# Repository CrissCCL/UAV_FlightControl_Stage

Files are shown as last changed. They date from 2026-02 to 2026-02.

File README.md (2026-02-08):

# 🧠🛩️ UAV Flight Control Stage — Teensy Carrier + Dual IMU (I2C)








## Overview

This repository documents the **Flight Control Stage PCB**, a custom carrier board
designed to integrate sensing, command, and actuation interfaces for a modular UAV platform.

The goal of this stage is to provide a **clean and reliable hardware foundation**
for embedded flight control electronics, concentrating all signal routing and I/O
on a dedicated board while keeping the **power distribution stage electrically separated**.

This revision replaces the previous single-IMU layout with a **redundant dual-IMU
architecture (BMI088 + ICM-42605)** connected through independent I²C buses to improve
measurement reliability and fault tolerance.

This hardware revision has been validated using a **Teensy 4.0** microcontroller as the target flight-control MCU.

## 📂 Contents

- `/Hardware` → Schematics, PCB layout, Gerbers
- `/test_dual_angle_failover` → Embedded test firmware (dual-IMU fault injection, validation utilities)

## 🧩 System Architecture

<p align="center">
  
</p>

## 🧩 Modular UAV Architecture

The UAV electronics are intentionally divided into **two independent hardware stages**:

| Stage | Responsibility |
|---|---|
| **Flight Control Stage (this repo)** | Sensing + control + I/O |
| **Power Stage** | Power distribution & regulation |

### Flight Control Stage Composition

This board integrates:

- Teensy 4.x carrier board (real-time control MCU)
- Dual IMU module (BMI088 + ICM-42605)
- RC input interface
- 4× PWM outputs for ESCs
- UART telemetry/debug

### Why separation?

Separating **control electronics** from **power electronics** provides:

- lower electrical noise coupling  
- improved signal integrity  
- safer power handling  
- easier maintenance and board replacement  
- faster hardware iteration

Dedicated power board:  
👉 https://github.com/CrissCCL/UAV_PowerStage

## ✨ Key Features

- Dual IMU redundancy (**BMI088 + ICM-42605**) over **I²C ×2**
- Real-time embedded control on Teensy 4.x
- 1× RC input
- 4× PWM outputs
- UART telemetry interface
- Physically isolated from power stage
- Mature **V5 hardware revision**, validated through multiple control iterations

## 🧪 Tested Platform

- **MCU:** Teensy 4.0  
- **Test mode:** Bench testing (no flight)  
- **Fault injection:** Firmware-controlled via UART  

## 🧪 Dual-IMU Fault Injection & Validation

To validate the robustness of the **redundant dual-IMU architecture**, a **firmware-based fault injection framework** was implemented on the Flight Control Stage.

Instead of relying on physical disconnections or uncontrolled hardware failures, IMU faults are **intentionally emulated in firmware**, enabling deterministic, repeatable, and safe validation of the sensing and fallback logic.

### 🎯 Validation Objectives

- Verify **fault detection** on each IMU (BMI088 / ICM-42605)
- Validate **primary / secondary IMU selection logic**
- Confirm correct **telemetry reporting** under fault conditions
- Observe system behavior during **degraded sensing scenarios**

### 🔧 Emulated Fault Modes

The firmware allows selective injection of failures on either IMU, including:

- IMU not responding (communication failure)
- Frozen sensor data (stuck output)
- Corrupted or invalid measurements
- Forced mismatch between redundant sensors

These modes reproduce realistic sensor failure scenarios without modifying or stressing the hardware.

### 🧠 System Behavior Under Test

During fault injection, the following mechanisms are evaluated:

- IMU health monitoring
- Mismatch detection between redundant sensors
- Automatic fallback to the alternate IMU
- Consistent reporting through UART telemetry and monitoring interfaces

This validation strategy allows early verification of **fault-tolerant sensing behavior** before flight testing.

### ✅ Benefits of Firmware-Based Fault Injection

- Fully repeatable and controllable tests  
- No physical stress on sensors or connectors  
- Faster validation cycles  
- Increased confidence in flight-control sensing reliability  

> This approach is a key step toward a **robust and maintainable flight control sensing architecture**, suitable for real-world UAV operation.

### 📈 Experimental Results — IMU Fault Injection

The following plot shows the system response during **firmware-emulated IMU fault scenarios**.

It illustrates:

- Real-time attitude estimation from both IMUs
- Detection of inconsistent or invalid sensor data
- Automatic switching between primary and secondary IMU
- Continuity of the estimated state during sensor failure events

<p align="center">
  imu_failover_test
</p>

<p align="center">
  <sub>
    Dual-IMU fault injection test — mismatch detection and automatic IMU fallback under emulated failure conditions
  </sub>
</p>
> Note: The test was performed with the UAV mechanically fixed on a test bench.
> IMU failures were emulated in firmware to ensure repeatability, safety, and deterministic validation.

During the test, faults were injected dynamically via firmware commands, without any hardware disconnection.
The system maintained valid state estimation while transparently switching between sensors, confirming the
correct operation of the redundancy and failover logic.

### 🧾 Fault Injection Control Interface (Serial Commands)

IMU fault scenarios are triggered via **serial commands**, allowing controlled and repeatable testing without hardware modification.

Faults are injected at runtime through the **UART serial monitor**, using newline-terminated commands (`\n`).

#### Supported Commands
- F0 -> No fault (normal operation)
- F1 -> BMI088 dead (bmi_data_ok = 0)
- F2 -> ICM-42605 dead (icm_data_ok = 0)
- F3 -> BMI088 data corruption (forces mismatch)
- F4 -> ICM-42605 data corruption
- F5 -> BMI088 stuck output (frozen data)
- F6 -> ICM-42605 stuck output (frozen data)
- F3,5000 -> Apply F3 for 5000 ms, then automatically return to F0

#### Usage Notes

- All commands must be terminated with `\n`
- Timed fault injection (`Fx,<time_ms>`) allows transient failure testing
- Commands can be issued dynamically during operation
- No hardware reset or reconnection is required between tests

This interface enables **deterministic validation of IMU redundancy, fault detection, and failover behavior** under realistic failure conditions.

> The firmware implementation for fault injection is available under `/test_dual_angle_failover/`.

## 🔌 Hardware Interfaces

| Interface | Qty | Description |
|---|----|---|
| Dual IMU (BMI088 + ICM-42605) | 1 | Two independent I²C buses |
| RC Input | 1 | Pilot command |
| PWM Outputs | 4 | Propulsion control |
| UART | 1 | Telemetry / debug |
| Teensy Socket | 1 | MCU carrier |

## 🖼️ PCB Render Visualization

<table>
  <tr>
    <td align="center">
      flight control stage top<br>
      <sub>Top View</sub>
    </td>
    <td align="center">
      flight control stage bottom<br>
      <sub>Bottom View</sub>
    </td>
  </tr>
</table>

## ⚡ Physical Prototype (V5 Installed on UAV)

The **V5 prototype** is directly integrated into the UAV for **full-system validation**.

Given the maturity of the control architecture, this stage is deployed directly for:

- flight control testing  
- system integration  
- real-time experimentation  

The following image shows the complete setup of the **prototype version V1**:

<table>
  <tr>
    <td align="center">
      light control stage<br>
      <sub> light control stage </sub>
    </td>
    <td align="center">
        Flight control stage + MCU<br>
      <sub> Flight control stage + MCU </sub>
    </td>
  </tr>
</table>

## 🔗 Related Repositories

- UAV platform main repository: https://github.com/CrissCCL/DIY_UAV
- Power stage PCB: https://github.com/CrissCCL/UAV_PowerStage
- Dual IMU evaluation module (sensor characterization and early validation):  
  https://github.com/CrissCCL/UAV_Dual_IMU

## ⚠️ Disclaimer

Educational and experimental use only.
Always follow safe practices when working with UAV propulsion systems.

## 🤝 Support Projects

Support my work on Patreon:  
https://www.patreon.com/c/CrissCCL

## 📜 License

MIT License

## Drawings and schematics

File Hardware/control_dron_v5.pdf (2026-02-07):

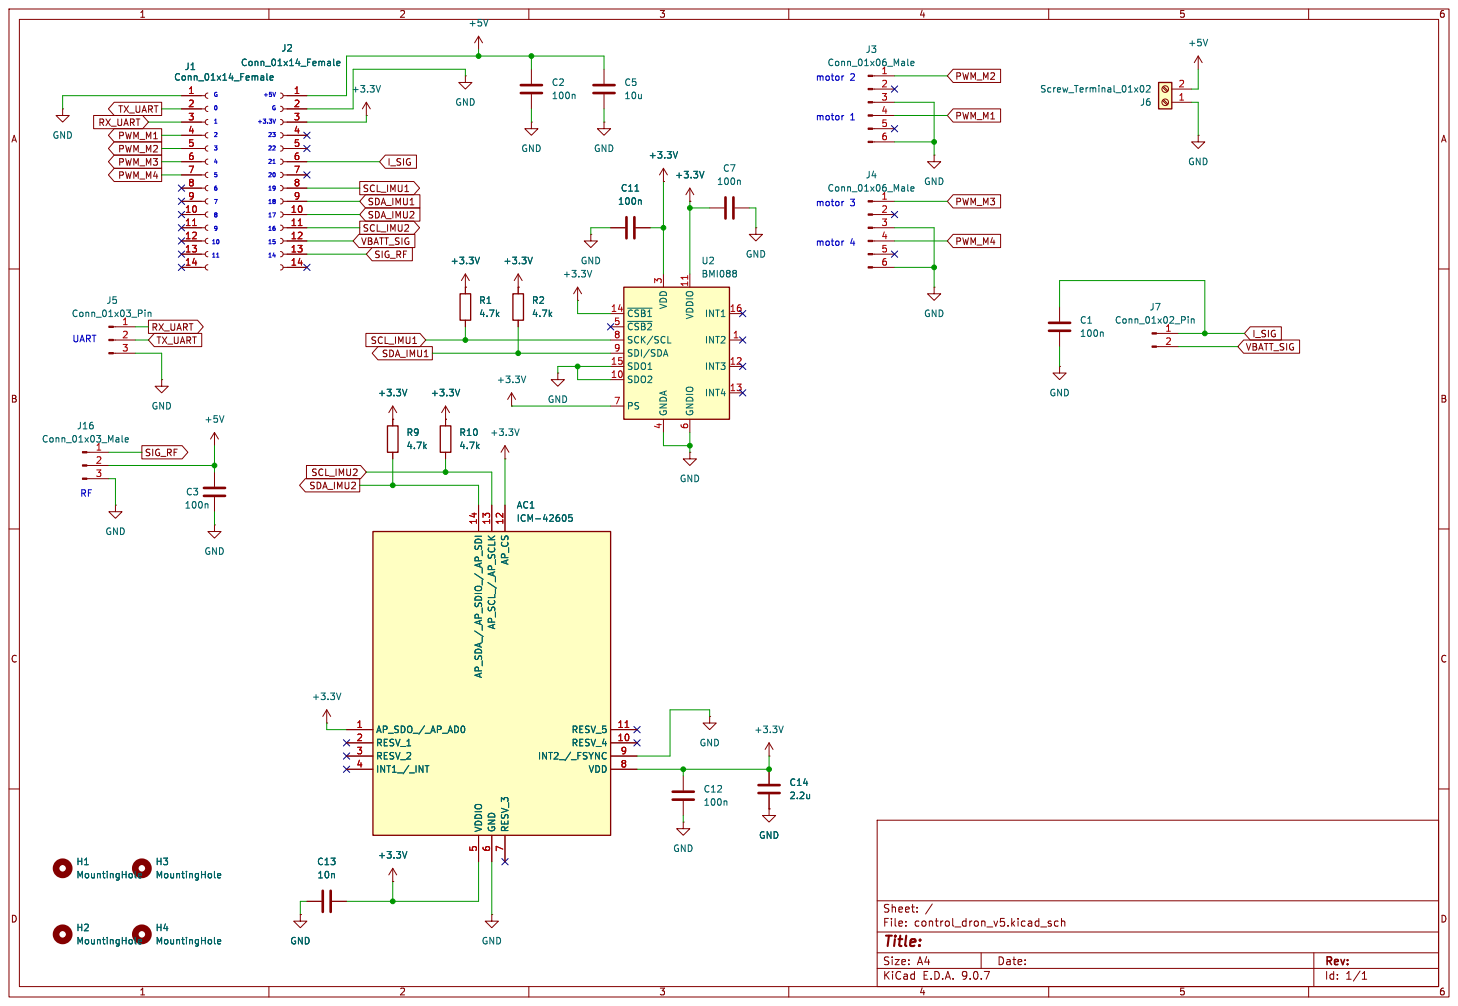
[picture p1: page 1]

Id: 1/1 Title: File: control_dron_v5.kicad_sch Sheet: /

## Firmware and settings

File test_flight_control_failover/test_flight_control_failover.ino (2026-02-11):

#include <Arduino.h>
#include <Wire.h>
#include <string.h>
#include <stdlib.h>

// ---- FIX Arduino autoprototyper (DO NOT DELETE) ----
enum FaultMode : uint8_t;
enum ImuSelect : uint8_t;
// -----------------------------------------------

/*
  =====================================================
  Dual IMU (BMI088 + ICM-42605) + Auto Failover + Fault Injection (Serial "F")
  Target: Teensy 4.x

  FIX applied:
  - Robust IMU init (ping + retries + proper post-reset delays)
  - ICM WHO_AM_I polling after reset (main cause of false FAIL at boot)
  =====================================================
*/

// =====================================================
// IMU selection
// =====================================================
enum ImuSelect : uint8_t { IMU_PRIMARY_BMI = 0, IMU_PRIMARY_ICM = 1 };
static ImuSelect PRIMARY_IMU = IMU_PRIMARY_BMI;

// =====================================================
// Fault injection
// =====================================================
enum FaultMode : uint8_t {
  FAULT_NONE = 0,
  FAULT_BMI_DEAD = 1,
  FAULT_ICM_DEAD = 2,
  FAULT_BMI_CORRUPT = 3,
  FAULT_ICM_CORRUPT = 4,
  FAULT_BMI_STUCK = 5,
  FAULT_ICM_STUCK = 6
};

static FaultMode faultMode = FAULT_NONE;
static uint32_t fault_until_ms = 0; // 0=infinite

static void set_fault(FaultMode m, uint32_t duration_ms) {
  faultMode = m;
  fault_until_ms = (duration_ms > 0) ? (millis() + duration_ms) : 0;
}

static void fault_tick_auto_clear() {
  if (fault_until_ms != 0 && (int32_t)(millis() - fault_until_ms) >= 0) {
    faultMode = FAULT_NONE;
    fault_until_ms = 0;
  }
}

// =====================================================
// I2C addresses
// =====================================================
static const uint8_t BMI_ACC_ADDR = 0x18;
static const uint8_t BMI_GYR_ADDR = 0x68;
static const uint8_t ICM_ADDR     = 0x69;

static const uint32_t I2C0_FREQ = 400000; // Wire
static const uint32_t I2C1_FREQ = 100000; // Wire1 robust

// =====================================================
// State flags
// =====================================================
bool bmi_ok=false, icm_ok=false;
bool bmi_data_ok=false, icm_data_ok=false;

// Units per IMU (AFTER fault)
float bmi_ax=0,bmi_ay=0,bmi_az=0, bmi_gx=0,bmi_gy=0,bmi_gz=0;
float icm_ax=0,icm_ay=0,icm_az=0, icm_gx=0,icm_gy=0,icm_gz=0;

// RAW copies (BEFORE fault) -> for reliable gating
static float bmi_ax_raw=0,bmi_ay_raw=0,bmi_az_raw=0, bmi_gx_raw=0,bmi_gy_raw=0,bmi_gz_raw=0;
static float icm_ax_raw=0,icm_ay_raw=0,icm_az_raw=0, icm_gx_raw=0,icm_gy_raw=0,icm_gz_raw=0;

// Helpers
static inline int16_t le16(uint8_t lsb, uint8_t msb) { return (int16_t)((msb << 8) | lsb); }
static inline int16_t be16(uint8_t msb, uint8_t lsb) { return (int16_t)((msb << 8) | lsb); }
static inline float   rad2deg(float r){ return r * 57.2957795f; }

static bool retry_bool(bool (*fn)(), int tries, uint32_t delay_ms) {
  for (int i=0;i<tries;i++) {
    if (fn()) return true;
    if (delay_ms) delay(delay_ms);
  }
  return false;
}

// =====================================================
// BMI regs
// =====================================================
static const uint8_t BMI_ACC_DATA_X_L  = 0x12;
static const uint8_t BMI_ACC_RANGE     = 0x41;
static const uint8_t BMI_ACC_PWR_CONF  = 0x7C;
static const uint8_t BMI_ACC_PWR_CTRL  = 0x7D;
static const uint8_t BMI_ACC_SOFTRESET = 0x7E;

static const uint8_t BMI_GYR_RATE_X_L  = 0x02;
static const uint8_t BMI_GYR_RANGE     = 0x0F;
static const uint8_t BMI_GYR_BANDWIDTH = 0x10;
static const uint8_t BMI_GYR_LPM1      = 0x11;
static const uint8_t BMI_GYR_SOFTRESET = 0x14;

// =====================================================
// ICM regs
// =====================================================
static const uint8_t ICM_BANK_SEL       = 0x76;
static const uint8_t ICM_DEVICE_CONFIG  = 0x11;
static const uint8_t ICM_WHO_AM_I       = 0x75; // expected 0x42
static const uint8_t ICM_INTF_CONFIG1   = 0x4D;
static const uint8_t ICM_PWR_MGMT0      = 0x4E;
static const uint8_t ICM_GYRO_CONFIG0   = 0x4F;
static const uint8_t ICM_ACCEL_CONFIG0  = 0x50;
static const uint8_t ICM_ACCEL_DATA_X1  = 0x1F;
static const uint8_t ICM_GYRO_DATA_X1   = 0x25;

// =====================================================
// Wire helpers (BMI)
// =====================================================
static bool w_ping(uint8_t addr) {
  Wire.beginTransmission(addr);
  return (Wire.endTransmission(true) == 0);
}

static bool w_write8(uint8_t addr, uint8_t reg, uint8_t val) {
  Wire.beginTransmission(addr);
  Wire.write(reg); Wire.write(val);
  return (Wire.endTransmission(true) == 0);
}

static bool w_readN(uint8_t addr, uint8_t startReg, uint8_t *buf, size_t n) {
  Wire.beginTransmission(addr);
  Wire.write(startReg);
  if (Wire.endTransmission(false) != 0) return false;
  size_t got = Wire.requestFrom((int)addr, (int)n);
  if (got != n) return false;
  for (size_t i=0;i<n;i++) buf[i]=Wire.read();
  return true;
}

// =====================================================
// Wire1 helpers (ICM)
// =====================================================
static bool w1_ping(uint8_t addr) {
  Wire1.beginTransmission(addr);
  return (Wire1.endTransmission(true) == 0);
}

static bool w1_write8_stop(uint8_t addr, uint8_t reg, uint8_t val) {
  Wire1.beginTransmission(addr);
  Wire1.write(reg); Wire1.write(val);
  return (Wire1.endTransmission(true) == 0);
}

static bool w1_read8_stop(uint8_t addr, uint8_t reg, uint8_t &val) {
  Wire1.beginTransmission(addr);
  Wire1.write(reg);
  if (Wire1.endTransmission(true) != 0) return false;
  delayMicroseconds(80);
  if (Wire1.requestFrom((int)addr, 1) != 1) return false;
  val = Wire1.read();
  return true;
}

static bool w1_read6_bytewise(uint8_t addr, uint8_t startReg, uint8_t out6[6]) {
  for (int i=0;i<6;i++) {
    if (!w1_read8_stop(addr, startReg + i, out6[i])) return false;
  }
  return true;
}

// =====================================================
// BMI init + read (ROBUST)
// =====================================================
static bool bmi_acc_reset_step() { return w_write8(BMI_ACC_ADDR, BMI_ACC_SOFTRESET, 0xB6); }

static bool bmi_acc_cfg_step() {
  if (!w_write8(BMI_ACC_ADDR, BMI_ACC_PWR_CONF, 0x00)) return false;
  delay(2);
  if (!w_write8(BMI_ACC_ADDR, BMI_ACC_PWR_CTRL, 0x04)) return false;
  delay(10);
  if (!w_write8(BMI_ACC_ADDR, BMI_ACC_RANGE, 0x01)) return false;
  return true;
}

static bool bmi_gyr_reset_step() { return w_write8(BMI_GYR_ADDR, BMI_GYR_SOFTRESET, 0xB6); }

static bool bmi_gyr_cfg_step() {
  if (!w_write8(BMI_GYR_ADDR, BMI_GYR_LPM1, 0x00)) return false;
  delay(2);
  if (!w_write8(BMI_GYR_ADDR, BMI_GYR_RANGE, 0x00)) return false;
  if (!w_write8(BMI_GYR_ADDR, BMI_GYR_BANDWIDTH, 0x02)) return false;
  return true;
}

static bool bmi_init_robust() {
  if (!w_ping(BMI_ACC_ADDR)) return false;
  if (!w_ping(BMI_GYR_ADDR)) return false;

  if (!retry_bool(bmi_acc_reset_step, 5, 2)) return false;
  delay(50); // important after accel reset
  if (!retry_bool(bmi_acc_cfg_step, 5, 5)) return false;

  if (!retry_bool(bmi_gyr_reset_step, 5, 5)) return false;
  delay(80); // important after gyro reset
  if (!retry_bool(bmi_gyr_cfg_step, 5, 5)) return false;

  return true;
}

static bool bmi_read_units(float &ax_g, float &ay_g, float &az_g,
                           float &gx_dps, float &gy_dps, float &gz_dps) {
  uint8_t a[6], g[6];
  if (!w_readN(BMI_ACC_ADDR, BMI_ACC_DATA_X_L, a, 6)) return false;
  if (!w_readN(BMI_GYR_ADDR, BMI_GYR_RATE_X_L, g, 6)) return false;

  int16_t ax = le16(a[0],a[1]);
  int16_t ay = le16(a[2],a[3]);
  int16_t az = le16(a[4],a[5]);

  int16_t gx = le16(g[0],g[1]);
  int16_t gy = le16(g[2],g[3]);
  int16_t gz = le16(g[4],g[5]);

  const float ACC_LSB_PER_G   = 5460.0f;
  const float GYR_LSB_PER_DPS = 16.4f;

  ax_g = (float)ax / ACC_LSB_PER_G;
  ay_g = (float)ay / ACC_LSB_PER_G;
  az_g = (float)az / ACC_LSB_PER_G;

  gx_dps = (float)gx / GYR_LSB_PER_DPS;
  gy_dps = (float)gy / GYR_LSB_PER_DPS;
  gz_dps = (float)gz / GYR_LSB_PER_DPS;
  return true;
}

// =====================================================
// ICM init + read (ROBUST)
// =====================================================
static bool icm_bank0_step() { return w1_write8_stop(ICM_ADDR, ICM_BANK_SEL, 0x00); }
static bool icm_reset_step() { return w1_write8_stop(ICM_ADDR, ICM_DEVICE_CONFIG, 0x01); }
static bool icm_i3c_off_step() { return w1_write8_stop(ICM_ADDR, ICM_INTF_CONFIG1, 0x01); }

static bool icm_cfg_step() {
  if (!w1_write8_stop(ICM_ADDR, ICM_GYRO_CONFIG0,  0x06)) return false;
  if (!w1_write8_stop(ICM_ADDR, ICM_ACCEL_CONFIG0, 0x06)) return false;
  return true;
}

static bool icm_pwr_on_step() { return w1_write8_stop(ICM_ADDR, ICM_PWR_MGMT0, 0x0F); }

static bool icm_init_robust() {
  if (!w1_ping(ICM_ADDR)) return false;

  if (!retry_bool(icm_bank0_step, 5, 2)) return false;
  delay(2);

  if (!retry_bool(icm_reset_step, 5, 5)) return false;
  delay(80); // main fix vs 3ms

  if (!retry_bool(icm_bank0_step, 5, 2)) return false;
  delay(2);

  // WHO_AM_I polling (main fix)
  uint8_t who = 0;
  bool who_ok = false;
  for (int i=0;i<20;i++) { // up to ~200ms
    if (w1_read8_stop(ICM_ADDR, ICM_WHO_AM_I, who) && who == 0x42) { who_ok = true; break; }
    delay(10);
  }
  if (!who_ok) return false;

  (void)retry_bool(icm_i3c_off_step, 3, 2);
  delay(2);

  if (!retry_bool(icm_cfg_step, 5, 5)) return false;
  if (!retry_bool(icm_pwr_on_step, 5, 10)) return false;
  delay(100);

  return true;
}

static bool icm_read_units(float &ax_g, float &ay_g, float &az_g,
                           float &gx_dps, float &gy_dps, float &gz_dps) {
  (void)w1_write8_stop(ICM_ADDR, ICM_BANK_SEL, 0x00);
  delayMicroseconds(80);

  uint8_t pm=0;
  if (w1_read8_stop(ICM_ADDR, ICM_PWR_MGMT0, pm)) {
    if (pm != 0x0F) {
      (void)w1_write8_stop(ICM_ADDR, ICM_PWR_MGMT0, 0x0F);
      delay(70);
    }
  }

  uint8_t a[6], g[6];
  if (!w1_read6_bytewise(ICM_ADDR, ICM_ACCEL_DATA_X1, a)) return false;
  if (!w1_read6_bytewise(ICM_ADDR, ICM_GYRO_DATA_X1,  g)) return false;

  int16_t ax = be16(a[0],a[1]);
  int16_t ay = be16(a[2],a[3]);
  int16_t az = be16(a[4],a[5]);

  int16_t gx = be16(g[0],g[1]);
  int16_t gy = be16(g[2],g[3]);
  int16_t gz = be16(g[4],g[5]);

  const float ACC_LSB_PER_G   = 2048.0f;
  const float GYR_LSB_PER_DPS = 16.4f;

  ax_g = (float)ax / ACC_LSB_PER_G;
  ay_g = (float)ay / ACC_LSB_PER_G;
  az_g = (float)az / ACC_LSB_PER_G;

  gx_dps = (float)gx / GYR_LSB_PER_DPS;
  gy_dps = (float)gy / GYR_LSB_PER_DPS;
  gz_dps = (float)gz / GYR_LSB_PER_DPS;
  return true;
}

// =====================================================
// Init + update both
// =====================================================
static void imu_init() {
  Wire.begin();
  Wire.setClock(I2C0_FREQ);
  delay(10);

  Wire1.setSDA(17);
  Wire1.setSCL(16);
  Wire1.begin();
  Wire1.setClock(I2C1_FREQ);
  delay(10);

  // Try a few times overall (robust boot)
  bmi_ok = false;
  icm_ok = false;

  for (int k=0;k<3;k++) { if (bmi_init_robust()) { bmi_ok = true; break; } delay(50); }
  for (int k=0;k<3;k++) { if (icm_init_robust()) { icm_ok = true; break; } delay(50); }

  // Promote to OK if reads succeed anyway (avoids "FAIL but measures")
  if (!bmi_ok) {
    float ax,ay,az,gx,gy,gz;
    for (int k=0;k<5;k++) { if (bmi_read_units(ax,ay,az,gx,gy,gz)) { bmi_ok=true; break; } delay(5); }
  }
  if (!icm_ok) {
    float ax,ay,az,gx,gy,gz;
    for (int k=0;k<5;k++) { if (icm_read_units(ax,ay,az,gx,gy,gz)) { icm_ok=true; break; } delay(5); }
  }

  Serial.print("BMI init: "); Serial.println(bmi_ok ? "OK" : "FAIL");
  Serial.print("ICM init: "); Serial.println(icm_ok ? "OK" : "FAIL");
}

static void imu_update() {
  bmi_data_ok = bmi_read_units(bmi_ax,bmi_ay,bmi_az, bmi_gx,bmi_gy,bmi_gz);
  icm_data_ok = icm_read_units(icm_ax,icm_ay,icm_az, icm_gx,icm_gy,icm_gz);

  // Save RAW before applying faults
  bmi_ax_raw=bmi_ax; bmi_ay_raw=bmi_ay; bmi_az_raw=bmi_az;
  bmi_gx_raw=bmi_gx; bmi_gy_raw=bmi_gy; bmi_gz_raw=bmi_gz;

  icm_ax_raw=icm_ax; icm_ay_raw=icm_ay; icm_az_raw=icm_az;
  icm_gx_raw=icm_gx; icm_gy_raw=icm_gy; icm_gz_raw=icm_gz;
}

// =====================================================
// Complementary angles
// =====================================================
static float bmi_roll=0, bmi_pitch=0;
static float icm_roll=0, icm_pitch=0;
static uint32_t t_prev_us=0;
static const float ALPHA = 0.98f;

// =====================================================
// Mismatch + failover (motion gating)
// =====================================================
static const float MISMATCH_DEG   = 10.0f;
static const int   MISMATCH_HITS  = 15;
static const uint32_t FAILOVER_COOLDOWN_MS = 2000;

static int mismatch_counter = 0;
static bool imu_mismatch = false;
static uint32_t last_failover_ms = 0;

static const float GATE_GYRO_DPS = 60.0f;
static const float GATE_ACC_G    = 0.20f;

static bool is_dynamic_motion() {
  if (!(bmi_data_ok && icm_data_ok)) return false;

  float gB = sqrtf(bmi_gx_raw*bmi_gx_raw + bmi_gy_raw*bmi_gy_raw + bmi_gz_raw*bmi_gz_raw);
  float gI = sqrtf(icm_gx_raw*icm_gx_raw + icm_gy_raw*icm_gy_raw + icm_gz_raw*icm_gz_raw);
  float gMin = min(gB, gI);

  float aB = sqrtf(bmi_ax_raw*bmi_ax_raw + bmi_ay_raw*bmi_ay_raw + bmi_az_raw*bmi_az_raw);
  float aI = sqrtf(icm_ax_raw*icm_ax_raw + icm_ay_raw*icm_ay_raw + icm_az_raw*icm_az_raw);
  float aAvg = 0.5f * (aB + aI);

  return (gMin > GATE_GYRO_DPS) || (fabsf(aAvg - 1.0f) > GATE_ACC_G);
}

static void mismatch_update(float dRoll, float dPitch) {
  if (bmi_data_ok && icm_data_ok) {
    if (fabsf(dRoll) > MISMATCH_DEG || fabsf(dPitch) > MISMATCH_DEG) mismatch_counter++;
    else mismatch_counter--;
  } else {
    mismatch_counter++;
  }
  if (mismatch_counter < 0) mismatch_counter = 0;
  if (mismatch_counter > MISMATCH_HITS) mismatch_counter = MISMATCH_HITS;
  imu_mismatch = (mismatch_counter >= MISMATCH_HITS);
}

static bool primary_dead() {
  return (PRIMARY_IMU == IMU_PRIMARY_BMI) ? (!bmi_data_ok) : (!icm_data_ok);
}

static void force_failover_if_primary_dead() {
  if (!primary_dead()) return;

  if (PRIMARY_IMU == IMU_PRIMARY_BMI) {
    if (icm_data_ok) {
      PRIMARY_IMU = IMU_PRIMARY_ICM;
      last_failover_ms = millis();
      mismatch_counter = 0;
      imu_mismatch = false;
    }
  } else {
    if (bmi_data_ok) {
      PRIMARY_IMU = IMU_PRIMARY_BMI;
      last_failover_ms = millis();
      mismatch_counter = 0;
      imu_mismatch = false;
    }
  }
}

static void maybe_failover_on_mismatch() {
  if (!imu_mismatch) return;
  uint32_t now = millis();
  if (now - last_failover_ms < FAILOVER_COOLDOWN_MS) return;

  if (PRIMARY_IMU == IMU_PRIMARY_BMI) {
    if (icm_data_ok) {
      PRIMARY_IMU = IMU_PRIMARY_ICM;
      last_failover_ms = now;
      mismatch_counter = 0;
      imu_mismatch = false;
    }
  } else {
    if (bmi_data_ok) {
      PRIMARY_IMU = IMU_PRIMARY_BMI;
      last_failover_ms = now;
      mismatch_counter = 0;
      imu_mismatch = false;
    }
  }
}

// =====================================================
// Serial parser
// =====================================================
static void parse_serial_fault_cmd() {
  static char buf[48];
  static uint8_t idx=0;

  while (Serial.available()) {
    char c = (char)Serial.read();
    if (c == '\r') continue;

    if (c == '\n') {
      buf[idx] = '\0';
      idx = 0;

      if (buf[0] == 'F' || buf[0] == 'f') {
        int mode = atoi(buf + 1);
        int dur  = 0;

        char *comma = strchr(buf, ',');
        if (comma) dur = atoi(comma + 1);

        if (mode < 0) mode = 0;
        if (mode > 6) mode = 6;
        if (dur < 0) dur = 0;

        set_fault((FaultMode)mode, (uint32_t)dur);
      }
      continue;
    }

    if (idx < sizeof(buf)-1) buf[idx++] = c;
    else idx = 0;
  }
}

// =====================================================
// Apply fault effects AFTER reading sensors
// =====================================================
static void apply_faults() {
  static bool bmi_stuck_init=false, icm_stuck_init=false;
  static float bmi_ax_s,bmi_ay_s,bmi_az_s,bmi_gx_s,bmi_gy_s,bmi_gz_s;
  static float icm_ax_s,icm_ay_s,icm_az_s,icm_gx_s,icm_gy_s,icm_gz_s;

  const float CORRUPT_GYRO_BIAS_DPS = 25.0f;

  switch (faultMode) {
    case FAULT_NONE:
      bmi_stuck_init=false;
      icm_stuck_init=false;
      break;

    case FAULT_BMI_DEAD:
      bmi_data_ok = false;
      break;

    case FAULT_ICM_DEAD:
      icm_data_ok = false;
      break;

    case FAULT_BMI_CORRUPT:
      if (bmi_data_ok) {
        bmi_gx += CORRUPT_GYRO_BIAS_DPS;
        bmi_gy -= 0.7f * CORRUPT_GYRO_BIAS_DPS;
      }
      break;

    case FAULT_ICM_CORRUPT:
      if (icm_data_ok) {
        icm_gx -= CORRUPT_GYRO_BIAS_DPS;
        icm_gy += 0.7f * CORRUPT_GYRO_BIAS_DPS;
      }
      break;

    case FAULT_BMI_STUCK:
      if (bmi_data_ok) {
        if (!bmi_stuck_init) {
          bmi_ax_s=bmi_ax; bmi_ay_s=bmi_ay; bmi_az_s=bmi_az;
          bmi_gx_s=bmi_gx; bmi_gy_s=bmi_gy; bmi_gz_s=bmi_gz;
          bmi_stuck_init=true;
        }
        bmi_ax=bmi_ax_s; bmi_ay=bmi_ay_s; bmi_az=bmi_az_s;
        bmi_gx=bmi_gx_s; bmi_gy=bmi_gy_s; bmi_gz=bmi_gz_s;
      }
      break;

    case FAULT_ICM_STUCK:
      if (icm_data_ok) {
        if (!icm_stuck_init) {
          icm_ax_s=icm_ax; icm_ay_s=icm_ay; icm_az_s=icm_az;
          icm_gx_s=icm_gx; icm_gy_s=icm_gy; icm_gz_s=icm_gz;
          icm_stuck_init=true;
        }
        icm_ax=icm_ax_s; icm_ay=icm_ay_s; icm_az=icm_az_s;
        icm_gx=icm_gx_s; icm_gy=icm_gy_s; icm_gz=icm_gz_s;
      }
      break;
  }
}

// =====================================================
// Setup / Loop
// =====================================================
void setup() {
  Serial.begin(115200);
  delay(200);
  imu_init();
  t_prev_us = micros();
}

void loop() {
  parse_serial_fault_cmd();
  fault_tick_auto_clear();

  uint32_t t_now = micros();
  float dt = (t_now - t_prev_us) * 1e-6f;
  if (dt <= 0) dt = 0.005f;
  if (dt > 0.05f) dt = 0.005f;
  t_prev_us = t_now;

  imu_update();
  apply_faults();

  // Immediate failover if the primary dies
  force_failover_if_primary_dead();

  float bmi_roll_acc  = rad2deg(atan2f(bmi_ay, sqrtf(bmi_ax*bmi_ax + bmi_az*bmi_az)));
  float bmi_pitch_acc = -rad2deg(atan2f(bmi_ax, sqrtf(bmi_ay*bmi_ay + bmi_az*bmi_az)));

  float icm_roll_acc  = rad2deg(atan2f(icm_ay, sqrtf(icm_ax*icm_ax + icm_az*icm_az)));
  float icm_pitch_acc = -rad2deg(atan2f(icm_ax, sqrtf(icm_ay*icm_ay + icm_az*icm_az)));

  if (bmi_data_ok) {
    bmi_roll  = ALPHA*(bmi_roll  + bmi_gx*dt) + (1.0f-ALPHA)*bmi_roll_acc;
    bmi_pitch = ALPHA*(bmi_pitch + bmi_gy*dt) + (1.0f-ALPHA)*bmi_pitch_acc;
  }
  if (icm_data_ok) {
    icm_roll  = ALPHA*(icm_roll  + icm_gx*dt) + (1.0f-ALPHA)*icm_roll_acc;
    icm_pitch = ALPHA*(icm_pitch + icm_gy*dt) + (1.0f-ALPHA)*icm_pitch_acc;
  }

  float dRoll  = (bmi_data_ok && icm_data_ok) ? (bmi_roll  - icm_roll)  : 0.0f;
  float dPitch = (bmi_data_ok && icm_data_ok) ? (bmi_pitch - icm_pitch) : 0.0f;

  bool dyn = is_dynamic_motion();
  if (!dyn) {
    mismatch_update(dRoll, dPitch);
  } else {
    if (mismatch_counter > 0) mismatch_counter--;
    imu_mismatch = (mismatch_counter >= MISMATCH_HITS);
  }

  maybe_failover_on_mismatch();

  float rollP  = (PRIMARY_IMU == IMU_PRIMARY_BMI) ? bmi_roll  : icm_roll;
  float pitchP = (PRIMARY_IMU == IMU_PRIMARY_BMI) ? bmi_pitch : icm_pitch;

  static uint32_t t_print=0;
  if (millis() - t_print >= 10) {
    t_print = millis();

    // If you want STRICT CSV, replace prints with the CSV line described in header.
    Serial.print("P=");
    Serial.print(PRIMARY_IMU == IMU_PRIMARY_BMI ? "BMI" : "ICM");
    Serial.print("  ");

    Serial.print("BMI("); Serial.print(bmi_data_ok); Serial.print(") ");
    Serial.print("r,p="); Serial.print(bmi_roll,1); Serial.print(",");
    Serial.print(bmi_pitch,1);

    Serial.print("  ||  ");

    Serial.print("ICM("); Serial.print(icm_data_ok); Serial.print(") ");
    Serial.print("r,p="); Serial.print(icm_roll,1); Serial.print(",");
    Serial.print(icm_pitch,1);

    Serial.print("  ||  ");
    Serial.print("d="); Serial.print(dRoll,1); Serial.print(",");
    Serial.print(dPitch,1);

    Serial.print("  ||  ");
    Serial.print("MISMATCH="); Serial.print(imu_mismatch ? "YES" : "NO");
    Serial.print(" (cnt="); Serial.print(mismatch_counter); Serial.print(")");

    Serial.print("  ||  rollP,pitchP=");
    Serial.print(rollP,1); Serial.print(","); Serial.print(pitchP,1);

    Serial.print("  || fault=");
    Serial.print((int)faultMode);

    Serial.println();
  }
}
